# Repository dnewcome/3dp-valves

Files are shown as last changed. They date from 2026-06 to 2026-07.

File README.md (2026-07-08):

# 3dp-valves

A **parametric, 3D-printable solenoid valve & manifold system** for compressed gas —
shop air and (regulated, low-pressure) propane/butane for flame effects, plus pneumatic
cylinder control. Fluid schematics are modeled as composable solid parts in
[build123d](https://github.com/gumyr/build123d) and exported as clean, watertight STLs.

The idea: replace expensive miniature gas valves and manifolds with cheap printed blocks
that share a standard mating-face **port interface** (port + TPU gasket groove + bolt
pattern), so manifold configurations are assembled from composable blocks.

The repo now has two subsystems:
- **Valves** — direct-acting solenoid poppet valves + manifolds for compressed gas (below).
- **Pumps** — **two versions** of a solids-handling positive-displacement pump for fluids
  full of suspended solids (glass beads in mineral oil): a **horizontal S-valve** pump
  ([`PUMP.md`](PUMP.md)) and a **vertical submersible** rotary-distributor pump
  ([`VPUMP.md`](VPUMP.md)). Both are kept and maintained.

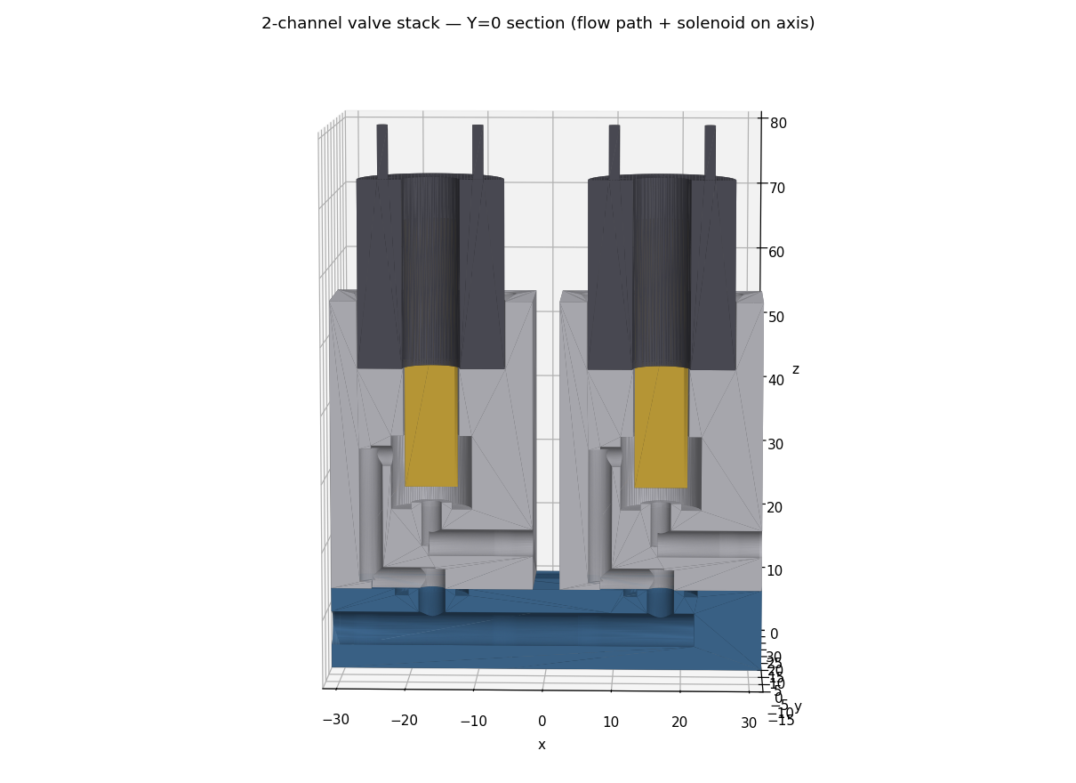
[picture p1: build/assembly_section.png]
2-channel valve stack, Y=0 section


## Design

A single channel is a **direct-acting, normally-closed, pressure-to-close poppet valve**:

```
  inlet (manifold, bottom) ─► -X riser ─► chamber  (supply surrounds the poppet)
                                              │  poppet lifts off the seat
                                              ▼
                                       orifice ─► +X outlet
```

- **Pressure-to-close** — supply fills the chamber and presses the poppet onto the seat,
  so pressure *helps* seal. The return spring is light (just reseats at zero pressure);
  the solenoid opens against P × orifice-area + spring, pulling from the seated position
  where the magnetic gap is smallest and coil force is greatest.
- **Direct-acting** (coil force only) — required for low-pressure / low-differential gas.
- **Normally-closed** — fail-safe (de-energized = shut).
- Tradeoff: the coil sets the max openable orifice (`A_max ≈ F_coil / P`) — generous at
  25 psi propane, tight (~Ø3) at 100 psi air. See [`BRIEF.md`](BRIEF.md).

See [`BRIEF.md`](BRIEF.md) for scope, [`RESEARCH.md`](RESEARCH.md) for solenoid/valve
selection and the duty-cycle / direct-vs-pilot reasoning, and
[`PRINT_AND_TEST.md`](PRINT_AND_TEST.md) for materials and the pressure-test procedure.

## Parts

| Module | Output | Material |
|---|---|---|
| `cad/interface.py` | shared port interface (constants, bolt pattern) | — |
| `cad/solenoid_block.py` | single valve body block | SLA rigid resin |
| `cad/poppet.py` | moving poppet | SLA rigid resin |
| `cad/tpu_disc.py` | flat sealing gasket | **FDM TPU ~95A** |
| `cad/manifold.py` | 1-inlet → 2-channel supply manifold | SLA rigid resin |
| `cad/solenoid_model.py` | reference coil + plunger (for fit only) | **bought, not printed** |
| `cad/assembly.py` | full + Y=0 section render (STL + PNG) | — |

Dimensions are chained by imports (`tpu_disc → poppet → solenoid_block → interface ←
manifold`), so changing one interface constant and rebuilding keeps every part in sync.

## Build

```bash
make deps        # pip install build123d trimesh matplotlib manifold3d
make             # build all parts + assembly/section render into build/
make help        # list targets (parts, assembly, clean, ...)
```

Or run a single script directly, e.g. `python3 cad/solenoid_block.py`. Each script
prints a sanity line (bounding box, body count, watertight flag). The Makefile tracks
the import chain, so editing `interface.py` rebuilds every dependent part.

## Pumps (solids-handling) — two versions

Where the valve blocks are all *small* precision orifices and poppet seats, the pumps are
the opposite — **large, clear, unobstructed passages** so suspended solids (glass beads in
mineral oil) never meet anything smaller than themselves. Both are positive-displacement,
run two cylinders 180° out of phase off one crankshaft, and share the same bead-safe parts
and clog guard (every wetted passage ≥ 4× the design bead, enforced at build). They differ
in orientation and directional valve:

| Version | Directional valve | Shaft | Best for | Port coverage | Docs |
|---|---|---|---|---|---|
| **Horizontal S-valve** | swinging **S-tube** | horizontal crank | bench / open-top hopper | ~41% (plain eccentric → wants a dwell cam) | [`PUMP.md`](PUMP.md) |
| **Vertical submersible** | coaxial **rotary distributor** | vertical shaft | running **submerged** | **~89%** (kidney arc = free dwell) | [`VPUMP.md`](VPUMP.md) |

A MuJoCo timing sim measures the port coverage of each (`sim/pump_sim.py`, `sim/vpump_sim.py`).

### Horizontal S-valve pump

A big swinging **S-tube** alternately connects each cylinder to the discharge — nothing
small to jam. The sim found a plain crank eccentric seals the discharging port only ~41% of
the cycle, so the swing wants a **dwell cam**. Full write-up in **[`PUMP.md`](PUMP.md)**.

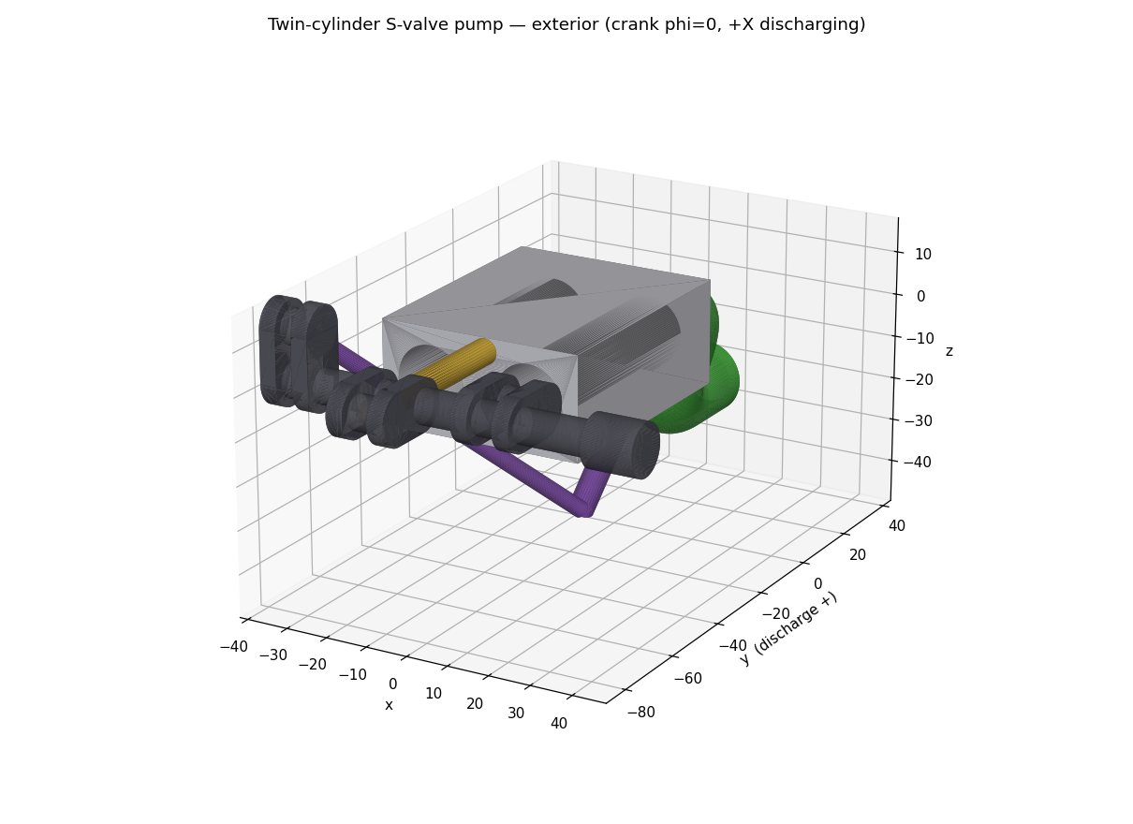
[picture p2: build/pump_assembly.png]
Twin-cylinder S-valve pump — exterior


```bash
make pump            # build the pump parts + assembly/section renders
make mujoco          # interactive timing sim (watch the swing track the ports)
```

### Vertical submersible pump

The vertical shaft makes the directional valve a **rotary distributor** coaxial with the
drive, which gives the dwell for free (**~89%** of the cycle sealed). Opposed cylinders,
90° up-piping, output riser to the surface. Full write-up in **[`VPUMP.md`](VPUMP.md)**.

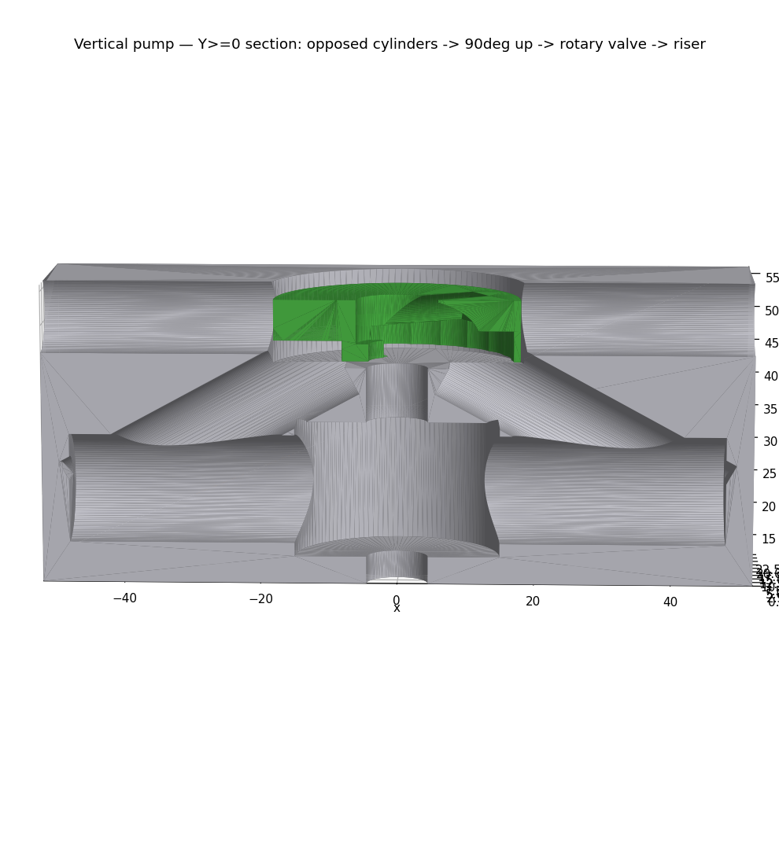
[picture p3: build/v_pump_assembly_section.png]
Vertical submersible pump — section


```bash
make vpump           # build the vertical submersible pump + renders
make vmujoco         # interactive timing sim of the rotary distributor (~89% coverage)
```

## Status

- **Valves:** working MVP — one complete sealed channel + a 2-channel manifold, all
  watertight. Next: print and pressure-test a single channel at 25 psi.
- **Pumps:** **two** working versions kept side by side — the horizontal S-valve pump
  ([`PUMP.md`](PUMP.md)) and the vertical submersible rotary-distributor pump
  ([`VPUMP.md`](VPUMP.md)). All parts watertight, timing simulated for both. Open details
  (dwell cam / rotary-union seal, hopper, bench test) are tracked in their docs.

Not yet modeled: the A/B + exhaust 2-way cylinder valve (pneumatics stretch) and a
schematic-driven manifold generator.

## Safety

Printed parts for **flammable gas**. Test with **air first**, never debug leaks with fuel
gas, use a regulator + leak detector, and run propane only outdoors with upstream shutoff.
Low-pressure, regulated service only.

## License

MIT

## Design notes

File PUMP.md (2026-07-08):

# Twin-cylinder S-valve pump (solids-handling)

A **parametric, 3D-printable positive-displacement pump** that moves fluids carrying
suspended solids — here **glass reflective beads in mineral oil** — without clogging.
It borrows the concrete-pump trick: the only "valve" is a **fat swinging tube** whose
bore is far bigger than any bead, so there is no small orifice or seat to jam. Built in
[build123d](https://github.com/gumyr/build123d), same conventions as the valve blocks.

> This is the **horizontal** version (bench / open-top hopper). For running the pump
> **submerged**, see the [**vertical submersible version**](VPUMP.md) — same bead-safe
> parts, a vertical shaft, and a coaxial rotary distributor. Both are maintained.

See [`PUMP_BRIEF.md`](PUMP_BRIEF.md) for scope/decisions.

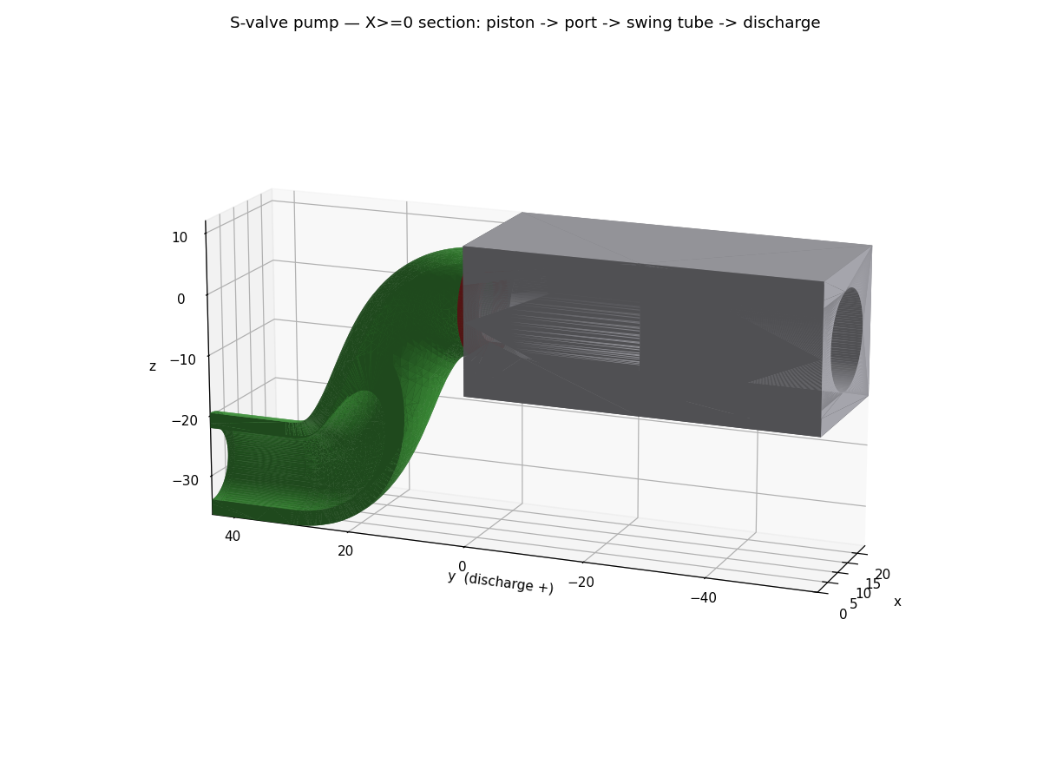
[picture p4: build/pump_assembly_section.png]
S-valve pump — X≥0 section: bore → wear ring → swing tube → discharge


## How it works

```
        hopper (open top, holds the bead-oil slurry, contains the S-tube)
   ┌──────────────────────────────────────────┐
   │   ●(-X port)            ●(+X port)         │  wear plate (y=0), two ports
   │        ╲                 ╱ ← S-tube mouth + TPU wear ring covers ONE port
   │         ╲_______________╱                  │
   │          (      S       ) gooseneck        │
   │           ╲____________╱                   │
   │             ▼ pivot = discharge axis ──────┼──► out
   └─────────────╫──────────────────────────────┘
   behind plate: two cylinders (bores along Y)
       piston ◄──┤├──► piston      ← 180° out of phase
                 ││
            conrods ─► ONE crankshaft ◄─ swing eccentric ─► rocks the S-tube
```

- **Two cylinders, 180° out of phase.** While one piston pushes slurry out through its
  port, the other retracts and **draws fresh slurry from the hopper** through its
  (uncovered) port. Output is near-continuous.
- **The S-tube is the whole valve.** Its outlet end is a fixed pivot on the discharge
  axis; its inlet **mouth swings** across the wear plate to cover exactly one port at a
  time. Because the mouth rides a circle centered on the pivot axis, and the plate is
  perpendicular to that axis, the mouth stays flat in the plate plane at **every** swing
  angle — one rigid tube seals two ports. Verified in `pump_assembly.py`: the swung
  mouth lands on the port at x=12.0, z=0.0.
- **Why it eats beads:** every bead-wetted passage — bore, port, tube — is ≥ **4× the
  design-max bead** (`pump_params.py` asserts `min_passage ≥ SAFETY × BEAD_D` at import,
  so the design *cannot* build if a passage is too narrow). Real glass reflective beads
  are much smaller than the 3 mm ceiling, so the margin is enormous.
- **Self-sealing wear ring.** A replaceable **TPU wear ring** on the mouth is pressed
  onto the plate by the discharge pressure itself. Mineral oil helps twice: it is
  viscous (keeps beads suspended, fills printed clearances) and lubricating (glass-in-oil
  grinds the seal far less than glass dry or in water). The ring is the designated wear
  item — print spares and swap it, exactly like the valve's `tpu_disc`.
- **One motor runs everything.** A single crankshaft reciprocates both pistons and, off a
  third eccentric, rocks the S-tube in time — no separate swing actuator.

## Parts

| Module | Output | Material |
|---|---|---|
| `cad/pump_params.py` | source of truth (dims, kinematics, `place()`, clog guard) | — |
| `cad/cylinder_block.py` | twin-cylinder body + wear plate + 2 ports | SLA rigid resin |
| `cad/s_tube.py` | swing tube (the S-valve) | SLA rigid resin |
| `cad/wear_ring.py` | replaceable mouth face seal | **FDM TPU ~95A** |
| `cad/piston.py` | piston (O-ring gland + conrod clevis) ×2 | SLA rigid resin |
| `cad/crankshaft.py` | single drive shaft (2 throws + swing eccentric) | printed or metal rod |
| `cad/pump_assembly.py` | full + X≥0 section render (STL + PNG) | — |

Dimensions chain from `pump_params.py` (like the valves' `interface.py`): change one
constant, rebuild, and every part + the assembly re-fit. Connecting rods and the swing
pushrod are drawn at assembly time as reference links between the crank pin centers.

## Build

```bash
make pump        # build all pump parts + assembly/section renders into build/
make             # build the valve stack AND the pump
python3 cad/pump_params.py    # print the clog-safety report (min passage vs bead)
```

Each part script prints a sanity line (bbox, body count, watertight). The assembly prints
a manifest, the swing-registration proof, and a bbox trip-wire. Renders are snapshotted to
`cad/renders/pump/` (a dated visual changelog — see its `INDEX.md`).

## Print, assemble, bench-test

**Materials / hardware (bench scale, default params):**
- Rigid parts (block, S-tube, pistons): **SLA** rigid resin (smooth bores/seal faces).
- Wear ring: **TPU ~95A** (FDM) or flexible SLA resin — must be an elastomer to seal.
- Per piston: an O-ring (~Ø12 × 2 mm CS) for the gland, a wrist pin, a connecting rod.
- Crankshaft: print it, or use a metal rod with printed cheeks for stiffness.
- A geared **DC/BLDC motor** (mineral oil is viscous → give yourself torque headroom).
- **Mineral-oil compatibility check (do before soaking):** PETG, TPU, and fully-cured
  SLA resin are generally fine with mineral oil; verify your specific resin/filament
  (soak a coupon for a few days and check for swelling/softening) before long runs.

**Bench test:**
1. Turn the crank **by hand** first, dry: confirm the pistons reciprocate 180° apart and
   the S-tube rocks fully onto each port at the piston dead-centers (this is the timing to
   get right — see below).
2. Fill the hopper with plain **mineral oil** (no beads yet). Hand-crank and confirm it
   primes and moves oil out the discharge with no leaks at the wear ring or walls.
3. Add **glass beads** to the slurry and repeat — watch for smooth, clog-free discharge.
   Then couple the motor.

## Drive timing — simulated (the risky bit)

The riskiest open question was whether a **single crankshaft** can rock the S-tube so its
mouth stays sealed on the *discharging* cylinder's port for that whole stroke. The MuJoCo
bench `sim/pump_sim.py` plays the real CAD meshes through the crank kinematics (imported
from `pump_params.py`) and measures **port coverage** — how far the mouth sits from the
discharging port vs crank angle.

swing timing: sine vs dwell

**Two findings — both change the drive design:**

1. **A plain eccentric will not do — you need dwell.** A simple crank eccentric gives
   *sinusoidal* swing: the mouth lines up on the port only for an instant at mid-stroke and
   is badly misaligned (up to ~12 mm) at the stroke ends — the discharging cylinder leaks
   back to the hopper most of its stroke. Quantified: the discharging port is sealed only
   **~41 %** of the cycle with a sine profile, vs **~82 %** with a dwell profile (parks the
   mouth on the port, flips fast at the dead centers where piston velocity ≈ 0 so little
   flow is lost). Run it: `make mujoco` (interactive), `make mujoco-demo` (gif + figure).
2. **The swing axis is perpendicular to the crank axis.** The crankshaft turns about **X**
   but the S-tube swings about **Y**, so a single in-plane pushrod *cannot* couple them
   (the schematic pushrod in the CAD render is exactly that — schematic). The swing needs a
   **right-angle take-off**: a bevel/crown gear driving a crank coaxial with the S-tube
   pivot, or a **dwell cam** on the crankshaft with a follower. The cam is attractive
   because it can bake the dwell profile from finding (1) directly into its shape.

**Design implication:** drive the pistons off the crankshaft as planned, but drive the
swing with a **dwell cam** (or an indexing mechanism) coaxial-ish with the pivot — not a
plain eccentric + pushrod. Widening the ports into **kidney slots** along the swing arc
buys extra overlap margin on top of the dwell.

## Status & next

Working first slice: block + swing S-tube + TPU wear ring + pistons + single crankshaft,
all watertight; the section proves the bead-safe flow path; the swing geometry is verified;
and the drive timing is simulated (above).

**Next, roughly in order:**
1. **Design the swing dwell mechanism** — a cam profile (or bevel-gear + rocker) that
   realizes the ~square-wave dwell the sim showed is needed, with a right-angle take-off
   from the crankshaft. Then re-sim to confirm ≥ ~90 % sealed.
2. **Hopper** — an open-top shell in front of the plate that holds the slurry and houses
   the swinging tube (its own part; currently omitted so the mechanism is visible).
3. **Discharge rotary seal** — a fixed collar the S-tube's discharge stub spins in.
4. **Kidney ports** — elongate the plate ports along the swing arc for overlap timing
   (round ports work; kidneys smooth the changeover).
5. **Scale to your beads** — set `BEAD_D` to your real bead size and rebuild; the clog
   guard keeps every passage safe automatically.

## Safety

Mineral oil is combustible (high flash point) and messy — this is **not** a food-safe or
pressure-rated device. Bench/art use at low head only. Contain spills; glass beads in oil
are slippery. If you ever swap to a volatile carrier, reassess everything.

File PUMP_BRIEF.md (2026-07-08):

# 3dp-pump — kickoff brief

A **solids-handling pump** subsystem for the 3dp-valves repo. Where the valve blocks
are all *small* precision orifices + poppet seats, the pump is the opposite: **large,
clear, unobstructed passages** so suspended solids never hit anything smaller than
themselves.

- **Problem:** Pump glass reflective beads suspended in **mineral oil** for an art
  project, with **zero clogging** — no bead-wetted passage or valve may ever narrow
  below the largest bead.
- **Done looks like:** One motor turns; two printed cylinders reciprocate 180° out of
  phase; a swinging **S-tube** valve alternately connects each cylinder to the outlet;
  bead-laden mineral oil moves continuously across the bench and **never jams**.
- **Not now:** High pressure/head, self-priming from a deep source, long-life / wear
  rating, and any flame-FX or existing-solenoid-valve integration. Bench scale,
  near-zero back-pressure.
- **First slice:** A parametric **twin-cylinder S-valve pump core** in build123d — two
  cylinder bores, the swing **S-tube**, and the **wear-plate + replaceable TPU
  wear-ring** sealing face — sized so every bead-wetted passage stays well above the
  largest bead, exporting clean watertight STLs. The pump analog of
  `solenoid_block.py` + `poppet.py`, reusing this repo's flat-TPU-seal trick.
- **Open question (riskiest):** The **swing-tube-to-wear-plate seal** on a *printed*
  part — can a pressure/spring-loaded TPU wear ring seal oil against a printed plate
  while beads sweep across it, and can a **single crankshaft** rock the S-tube in sync
  with the pistons (cam or second throw) rather than a separate actuator? Sim-able
  first with the repo's MuJoCo skill.
  - **Update (simulated, `sim/pump_sim.py`):** a plain eccentric gives *sinusoidal*
    swing that seals the discharging port only ~41 % of the cycle; a **dwell** profile
    gets ~82 %. And the swing axis (Y) is perpendicular to the crank axis (X), so the
    swing needs a **right-angle take-off + dwell cam**, not a plain pushrod. See
    [`PUMP.md`](PUMP.md) → *Drive timing*. Seal-against-abrasion is still open (bench test).

## Why the S-valve (swing tube), not a poppet/ball check

Concrete pumps move fluid full of rocks because the only "valve" is a **fat tube whose
bore is bigger than any rock**. The tube's outlet end is a fixed pivot at the discharge;
its inlet mouth swings across a **wear plate** with two kidney ports (one per cylinder),
connecting exactly one cylinder to the outlet while the other draws from the hopper. The
mouth seals against the plate via a **wear ring** loaded by discharge pressure —
self-sealing, but self-wearing (the caption "…that maybe seems like a great idea, but…").
Mineral oil is a *friendly* carrier here: viscous (keeps beads suspended, fills printed
clearances) and lubricating (glass-in-oil grinds the seal far less than glass dry/in
water).

## Key decisions locked
- **Architecture:** twin-piston + **S-tube swing valve** (positive displacement, large
  clear passages, near-continuous output).
- **Drive:** **single motor + crankshaft** — one shaft reciprocates both pistons 180°
  out of phase *and* rocks the S-tube in time (cam or second throw), so one motor runs
  everything.
- **Carrier / solids:** glass reflective beads in mineral oil, bench scale, low head.
- **Seal:** replaceable **TPU wear ring** on the swinging mouth against a printed wear
  plate (reuses the repo's TPU-seal material + method).
- **Materials check (before soaking):** confirm mineral-oil compatibility of the chosen
  print resin/filament (PETG, TPU, cured SLA are generally fine).

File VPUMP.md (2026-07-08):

# Vertical submersible S-valve pump (rotary distributor)

A **vertical-shaft variant** of the [twin-cylinder pump](PUMP.md), built to run **submerged**
with the drive shaft vertical. Re-orienting the shaft to vertical makes the directional
valve **coaxial** with the drive — so the "cam" that alternates the output becomes a
**rotary distributor** turning on the same shaft. That change also solves the horizontal
pump's timing problem for free: a continuously-rotating distributor is a square-wave
selector, so it holds the **dwell** the [sim](PUMP.md#drive-timing--simulated-the-risky-bit)
showed a plain eccentric can't.

Vertical pump — Y≥0 section: opposed cylinders → 90° up → rotary valve → riser

## How it works (bottom → top)

```
                    ▲ output riser (up to the surface, past the waterline)
                    │
         ┌──────────┴──────────┐  valve chamber
         │      [ROTOR]        │  rotary distributor keyed to the shaft:
         │   kidney → riser    │   ~160° kidney routes the DISCHARGING port up to the
         │   relief → bath     │   riser; opposite relief opens the OTHER port to the bath
         ├─────────┬───────────┤  valve plate: 2 ports (±X), 180° apart
   port ─┤  90° up-gallery     ├─ port      each cylinder's outer port turns UP + inward
         │         │           │
   [===piston→]  shaft  [←piston===]  two OPPOSED cylinders (bores along X), ports outward
         │   crank throw       │   one shared crank throw drives both, 180° out of phase
         └─────────┬───────────┘
                   │ shaft
                   ▼ motor coupling (sealed, at the bottom)
```

- **Vertical shaft, opposed cylinders.** Two collinear cylinders (bores along X) share one
  crank throw, so their pistons run 180° out of phase — one discharges while the other
  draws from the bath. Opposed (rather than side-by-side) because a *central* vertical shaft
  makes collinear cylinders a clean, zero-offset slider-crank with ports that land **180°
  apart** on the valve plate — exactly what the rotary distributor wants.
- **Rotary distributor = the "cam".** A rotor keyed to the shaft carries a ~160° **kidney**
  on its underside. As it turns, the kidney connects whichever port is discharging up
  through the rotor's central bore to the **riser**, while an opposite **relief** opens the
  other port to the bath for suction. No poppets, no check valves — nothing small to clog.
- **Dwell for free.** Because the kidney is a 160° arc, the discharging port stays connected
  for ~160° of every 180° stroke: **~89% of the cycle sealed** (`python3 cad/vpump_params.py`),
  versus **~41%** for the horizontal plain eccentric. The ~20° gaps land at the dead centers,
  where piston velocity ≈ 0 and little flow is lost.
- **90° internal piping.** Each cylinder's horizontal discharge turns **up** to the coaxial
  valve, so the output leaves **vertical — 90° to the cylinders** — and rises out of the fluid.
- **Submersible.** The whole body runs under the fluid; the un-selected cylinder simply
  draws from the surrounding bath (vent to the valve chamber). Every bead-wetted passage
  stays ≥ 4× the design bead (the clog guard in `vpump_params.py` includes the kidney slot).

## Drive timing — simulated

The MuJoCo bench `sim/vpump_sim.py` plays the **real vertical-pump meshes** through the crank
kinematics and measures the same port coverage the [horizontal bench](PUMP.md#drive-timing--simulated-the-risky-bit)
used — closing the loop: where a plain swinging eccentric sealed the discharging port only
**~41%** of the cycle, the coaxial rotary distributor holds it **~89%**, with no cam profile
to tune. The kidney's 160° arc *is* the dwell; the only gaps are the ~20° dead-bands at each
changeover, where piston velocity ≈ 0.

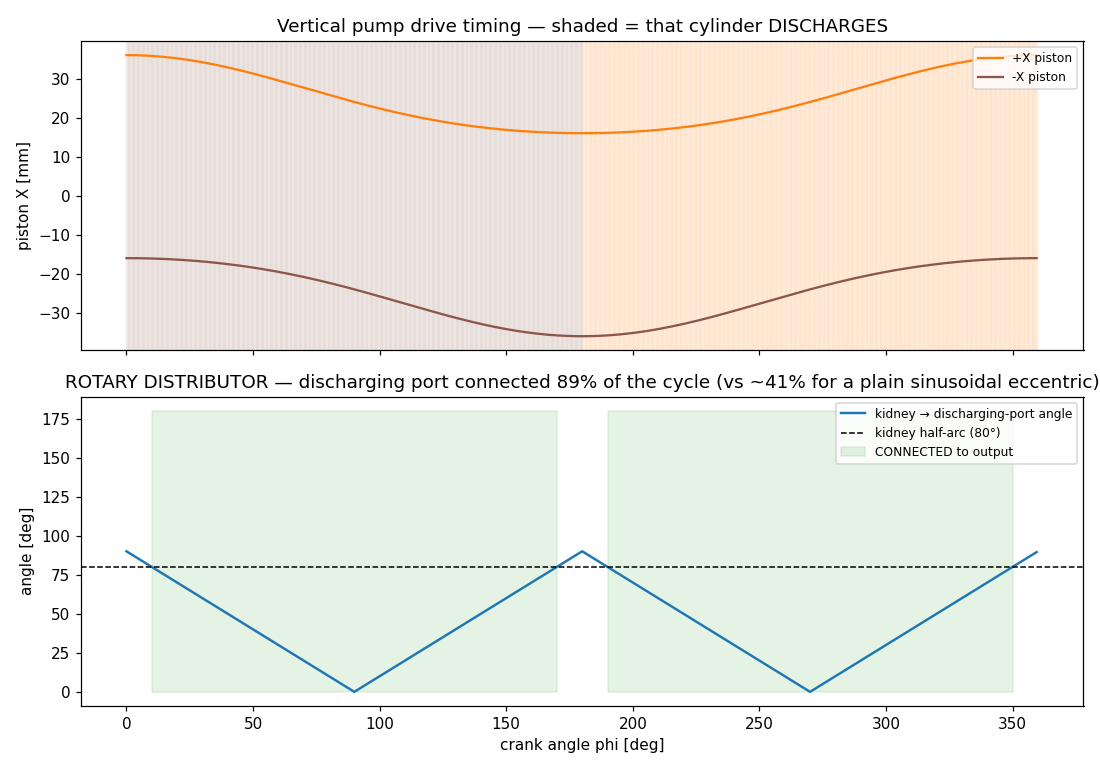
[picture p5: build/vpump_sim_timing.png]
vertical timing: rotary distributor coverage


```bash
make vmujoco          # interactive: watch the rotary valve track the discharging ports
make vmujoco-demo     # headless: coverage figure + animated gif
```

The interactive/gif view ghosts the block so the opposed pistons, crank, conrods, and the
green rotor are all visible turning inside the submersible body.

## Parts

| Module | Output | Notes |
|---|---|---|
| `cad/vpump_params.py` | source of truth (reuses bore/bead/piston consts + kinematics + clog guard) | — |
| `cad/v_block.py` | body: opposed bores + 90° galleries + valve plate + chamber | SLA rigid |
| `cad/v_rotor.py` | rotary distributor (kidney + suction relief + central output) | SLA rigid; wear item |
| `cad/v_crankshaft.py` | vertical shaft: crank throw + rotor key + coupling | printed or metal |
| `cad/piston.py` | piston ×2 (**reused** from the horizontal pump) | SLA rigid |
| `cad/v_pump_assembly.py` | vertical stack render + section + waterline | — |

```bash
make vpump                    # build the vertical pump parts + renders
python3 cad/vpump_params.py   # clog report + dwell coverage vs a plain eccentric
```

The assembly verifies the valve timing (the rotor kidney sits over whichever port is
discharging) before it renders.

## Decisions & honest open details (this is a v1 concept model)

Locked: vertical shaft · opposed cylinders + one crank throw · coaxial rotary distributor ·
90° up-galleries · riser output · submerged suction (no check valves).

Deliberately left for the next pass (documented so nothing reads as finished that isn't):
1. **Rotary-union seal.** The rotor's central output (rotating) meets the stationary riser
   at the top — that transfer needs a face seal (or an annular collector). Modeled as a
   straight hand-off here; a TPU face seal on the rotor top is the intended fix (same
   wear-item philosophy as the horizontal pump's ring).
2. **Motor placement.** Modeled **motor-below** (a sealed submersible unit at the bottom) so
   the output can rise straight up the center. For a **dry motor above the fluid**, the shaft
   runs up the center and the output takes an **offset riser** with a rotary transfer — a
   variant, not modeled yet. Say which you want and I'll build it.
3. **Suction vent detail.** The valve chamber vents to the bath through the block ends; the
   rotor's relief arc opens the non-selected port to it. The exact vent/relief sealing wants
   a bench check.
4. **Galleries** are modeled as straight routed passages (turning horizontal discharge up to
   the vertical valve); production would fillet/optimize them.
5. **Parallel vs opposed.** You picked "parallel"; I built **opposed** because a central
   vertical shaft makes it far cleaner (zero-offset slider-crank, ports naturally 180° apart
   for the rotary valve). Easy to switch to strict parallel with routed galleries if you want.

## Safety

Same as the [horizontal pump](PUMP.md#safety): mineral oil, bench/art use, low head, not
food-safe or pressure-rated. Submerged operation — keep the motor/electrics sealed and the
riser clear of the surface.

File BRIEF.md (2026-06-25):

# Flame-FX gas/pneumatic manifold — kickoff brief

- **Problem:** Sophisticated flame effects (and pneumatic cylinder control) normally
  need lots of expensive miniature gas valves + manifolds. Build a cheap, SLA-printed,
  parametric alternative where flow schematics become composable solid-modeled blocks.
- **Done looks like:** One printed inlet manifold block feeding **2 custom solenoid
  blocks**, each with a coil + ferrous plunger seating a TPU poppet against a printed
  seat, switching independent outputs on/off — holding 25 psi propane (target) /
  100 psi air (stretch).
- **Not now:** Gas-tightness of printed *walls* (SLA handles it); the A/B + exhaust
  2-way cylinder valve (stretch); full schematic→geometry compiler; flame-effect
  choreography / control electronics.
- **First slice:** A **single parametric solenoid block** in build123d — inlet/outlet
  ports, valve seat + orifice, TPU poppet groove, plunger guide bore, and coil bore —
  sized around one specific off-the-shelf coil + plunger, exporting a clean watertight
  STL. Get *one channel* sealing before manifolding two.
- **Open question (riskiest):** Coil pull vs. pressure on OPEN. With pressure-to-close
  (below), the spring is trivial but the solenoid must lift the poppet against
  P × orifice-area + spring. This caps the openable orifice: A_max ≈ F_coil / P.
  For a ~6 N coil (minus ~1 N spring): Ø6 at 25 psi (huge margin), but only ~Ø3 at
  100 psi. So Ø3 is comfortable for propane and right at the limit for 100 psi air —
  bigger pneumatic flow needs a bigger coil or a pilot/3-way (the A/B+exhaust stretch).

## Key decisions locked
- **Actuation:** Custom poppet + coil (fully parametric; we own sealing/force/spring).
- **Force orientation: PRESSURE-TO-CLOSE.** Supply fills the chamber and presses the
  poppet onto the seat, so pressure helps seal and the return spring is a light
  reseat-only spring (~0.5–1 N). The solenoid opens from the seated position, where
  the magnetic gap is smallest and coil force is greatest. (Beats pressure-to-open,
  where the spring is weakest exactly when it must hold against full pressure.)
- **Process:** SLA printing (good surface finish for seat/poppet sealing).
- **Pressures:** 25 psi propane (primary), 100 psi air/pneumatics (stretch).
- **Fallback under evaluation:** COTS miniature solenoid valves if custom poppet
  sealing proves unreliable.

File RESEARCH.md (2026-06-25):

# Solenoid & valve research

Research backing the actuation decisions in [BRIEF.md](BRIEF.md). Two paths:
the **custom poppet** (chosen) and a **COTS fallback** to de-risk sealing.

## Custom-poppet path — bare solenoids to design around

| Solenoid | Force / stroke | Duty | Notes |
|---|---|---|---|
| **Makermotor PN00121** (12V tubular push-pull) | 6N @ 10mm, 1.85A | continuous (listed) | Cheap (~$15–20), defined spec sheet — primary part to design around |
| **Generic 8mm-plunger push-pull** (Amazon/AliExpress) | 2–15N, 2–20mm stroke, 7–25W | continuous variants exist | Cheapest; specs vary by listing — buy & measure |
| **Murphy RP2307B / RP2309B** | 49–62N pull, 102–151N hold | continuous | Large/overkill, but shows pattern: hold force >> pull force |

**Key physics:** solenoid force is highest at end-of-stroke (smallest air gap).
A poppet seats at end-of-stroke — exactly where the coil is strongest. Design the
geometry so the magnetic gap is smallest at the sealed position. 100 psi × 3 mm
orifice ≈ 4.5 N seating force; the small 6 N unit clears it *if near-seated*.

## COTS fallback — drop-in valves if custom sealing flunks

**Propane / 25 psi:**
- **U.S. Solid 1/4" NPT brass + Viton, 12V NC** — rated water/gas/oil/fuel, ~$15–25. Credible cheap fallback.
- **AceCrew 1/2" Viton NC** — explicitly lists propane/butane.
- ⚠️ Most generic "12V solenoid valves" are water/air only (NBR) — NOT fuel-rated. Require Viton + brass/SS for propane.

**Pneumatics / 100 psi + A/B exhaust (stretch):**
- **SMC SY3000** / **Festo VUVG** — compact 3/2 & 5/2, base/manifold-mountable. Best integration path: printed block = manifold base, valve island bolts on. ~$30–60/valve.

## Three insights that shape the spec

1. **Direct-acting is mandatory.** Pilot-operated valves need ~5–10 psi differential to open; won't work at low pressure / zero flow. Custom poppet must be coil-force-only. Caps practical orifice size per coil.
2. **NC = fail-safe but fights continuous duty.** De-energized = closed (spring) is the safe default, but coil must stay energized to keep flow on, and cheap solenoids overheat held on. **Flame-FX poofers rescue this** — brief energization = intermittent duty, where small cheap solenoids thrive. *Held* pneumatic cylinders are the hard case (continuous-duty or latching coil).
3. **Latching/bistable solenoids** — pulse to switch, zero holding power, no heat. Good for held-open cases; adds driver complexity.
4. **Pressure-to-close, not pressure-to-open.** Orient the flow so supply pressure presses the poppet ONTO the seat (chamber = supply, orifice = outlet). Then the return spring only reseats at zero ΔP (light), and the coil opens from the seated gap where its force peaks. The opposite orientation makes the spring hold against pressure — and a compression spring is weakest when seated (least compressed), exactly when it must hold most. Cost of pressure-to-close: coil sets max orifice, A_max ≈ F_coil / P (≈Ø6 at 25 psi, ≈Ø3 at 100 psi for a 6 N coil).

**Net:** design the parametric block around a small continuous-duty 12V push-pull
(Makermotor-class), direct-acting, NC, **pressure-to-close** (gap-closes-at-seat) —
keep the U.S. Solid Viton valve as a drop-in fallback in the same manifold footprint.

## Sources
- Makermotor PN00121: https://makermotor.com/pn00121-12vdc-push-pull-solenoid-actuator-6n-at-10mm-stroke-1-85a/
- Murphy RP2307B: https://catalog.baileymotorequip.com/item/engine-controls/solenoid-drivers/item-1195
- Geeplus push-pull range: https://www.geeplus.com/push-pull-solenoids/
- U.S. Solid 1/4" brass Viton NC: https://ussolid.com/products/u-s-solid-electric-solenoid-valve-1-4-12v-dc-solenoid-valve-brass-body-normally-closed-viton-seal-html
- AceCrew Viton (propane/butane): https://www.amazon.com/VITON-Brass-Solenoid-Normally-Closed/dp/B07C627DVM
- SMC SY3000 5-port: https://www.smcusa.com/products/sy3000-5-port-solenoid-valve-all-types~128914
- Festo valves/manifolds: https://www.festo.com/us/en/c/products/industrial-automation/pneumatic-valves-and-valve-manifolds-id_pim23/
- Direct-acting vs pilot (min. differential): https://ussolid.com/blogs/solenoid-valve/differences-between-pilot-operated-and-direct-acting-solenoid-valves

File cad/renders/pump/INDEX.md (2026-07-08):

# pump render log

Visual changelog of the twin-cylinder S-valve pump. Newest at the bottom; never delete frames.

- 0001-core-exterior.png / 0001-core-section.png — 2026-07-07 — first slice: twin-cylinder
  block + swing S-tube + TPU wear ring + pistons + single crankshaft (2 opposed throws +
  swing eccentric). Section proves the bead-safe flow path bore -> port(ring) -> tube ->
  discharge. Swing geometry verified: mouth lands on the +X port.

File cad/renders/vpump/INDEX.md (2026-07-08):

# vertical submersible pump render log

- 0001-vertical-exterior.png / 0001-vertical-section.png — 2026-07-07 — first slice of the
  vertical submersible variant: opposed cylinders + one crank throw, coaxial rotary
  distributor (89% discharging-port coverage), 90° up-galleries, riser to the surface,
  motor-below. Timing verified (kidney over the discharging port).

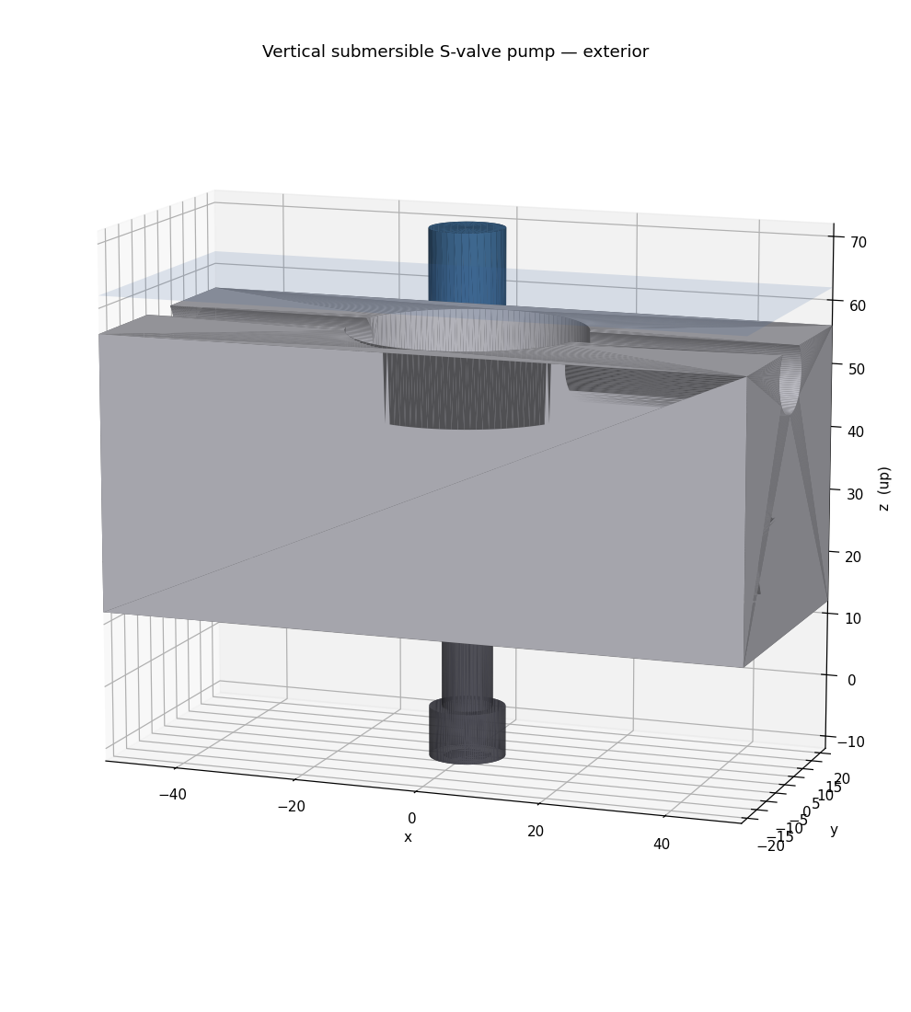
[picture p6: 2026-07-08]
cad/renders/vpump/0001-vertical-exterior.png

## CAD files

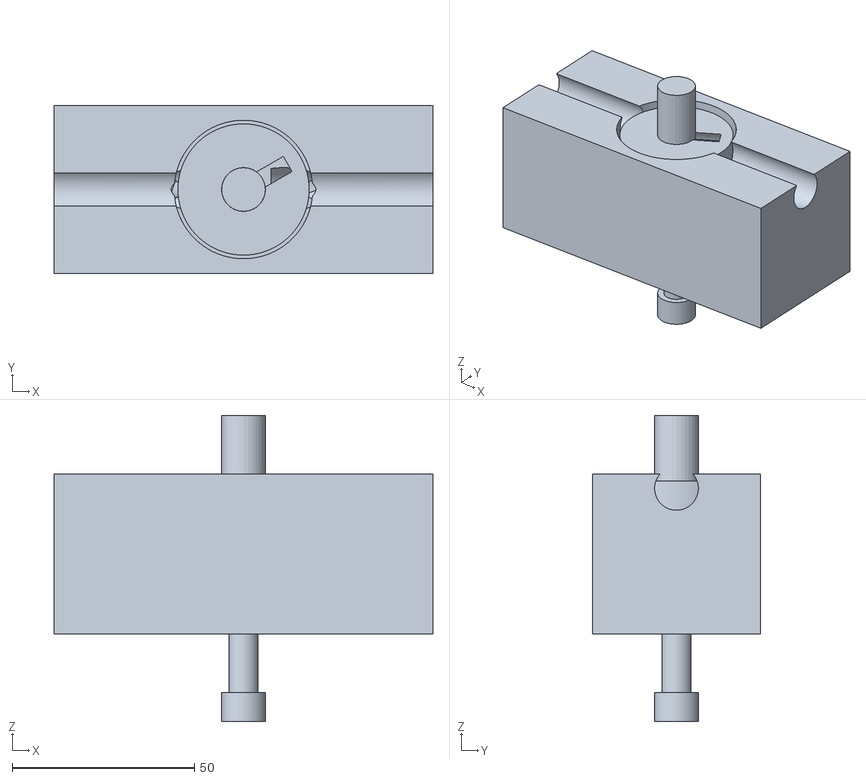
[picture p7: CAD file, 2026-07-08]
build/v_pump_assembly.stl
104.0 x 46.0 x 84.0

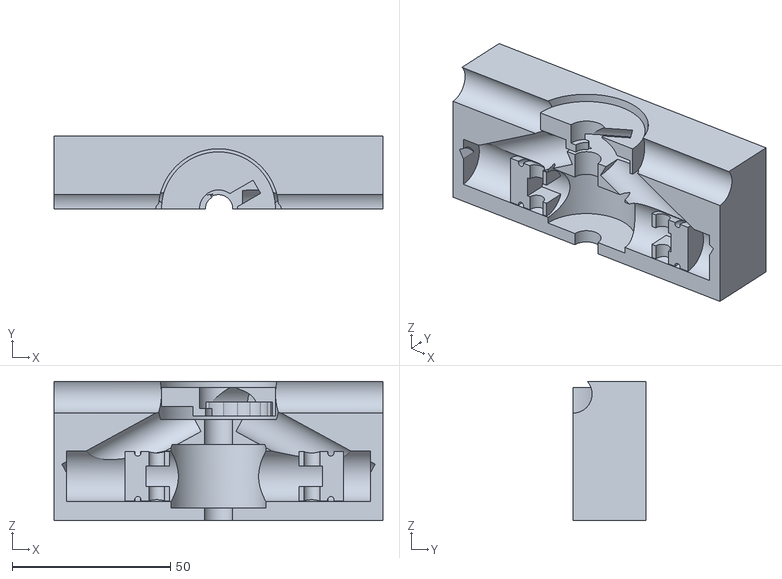
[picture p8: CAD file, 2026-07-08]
build/v_pump_assembly_section.stl
104.0 x 23.0 x 44.0

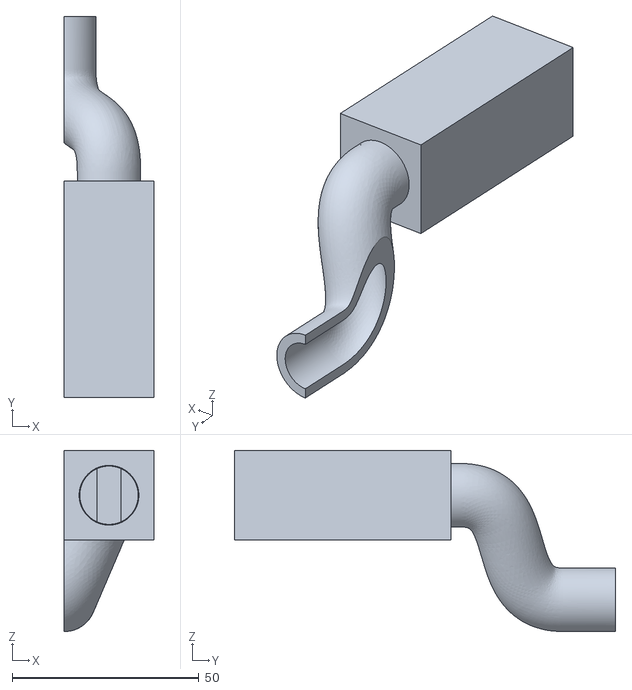
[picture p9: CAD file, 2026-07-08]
build/pump_assembly_section.stl
24.0 x 102.0 x 48.5

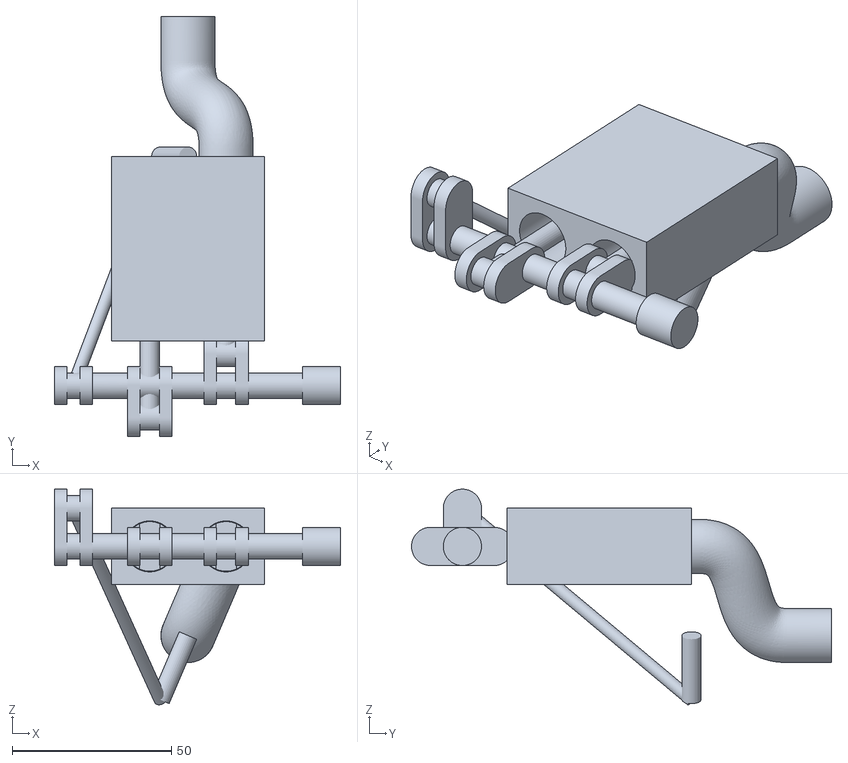
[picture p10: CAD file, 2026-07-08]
build/pump_assembly.stl
90.0 x 132.0 x 67.8

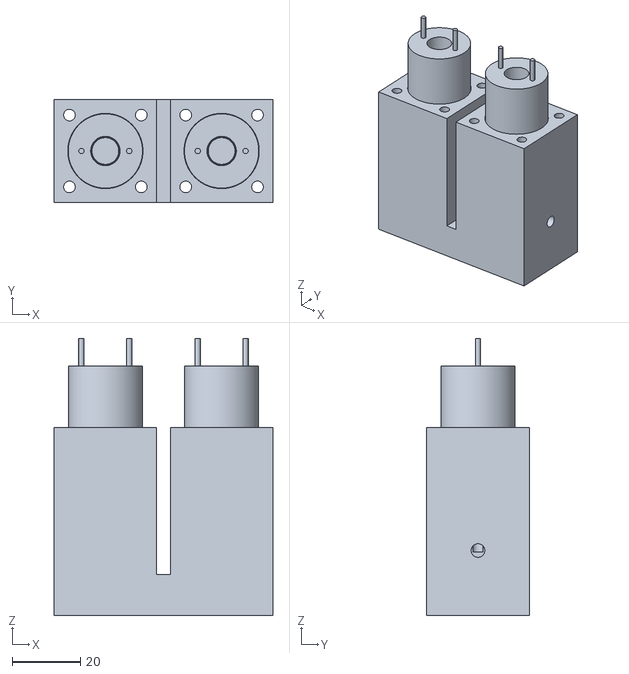
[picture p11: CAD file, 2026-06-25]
build/assembly.stl
64.0 x 30.0 x 81.0

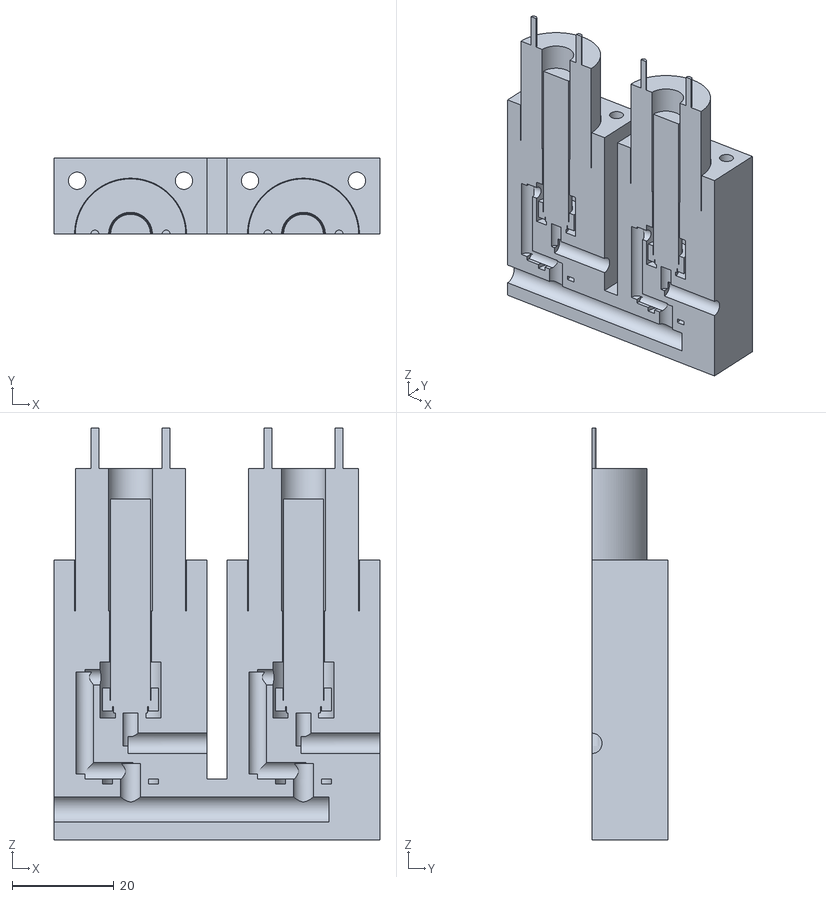
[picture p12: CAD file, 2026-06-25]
build/assembly_section.stl
64.0 x 15.0 x 81.0

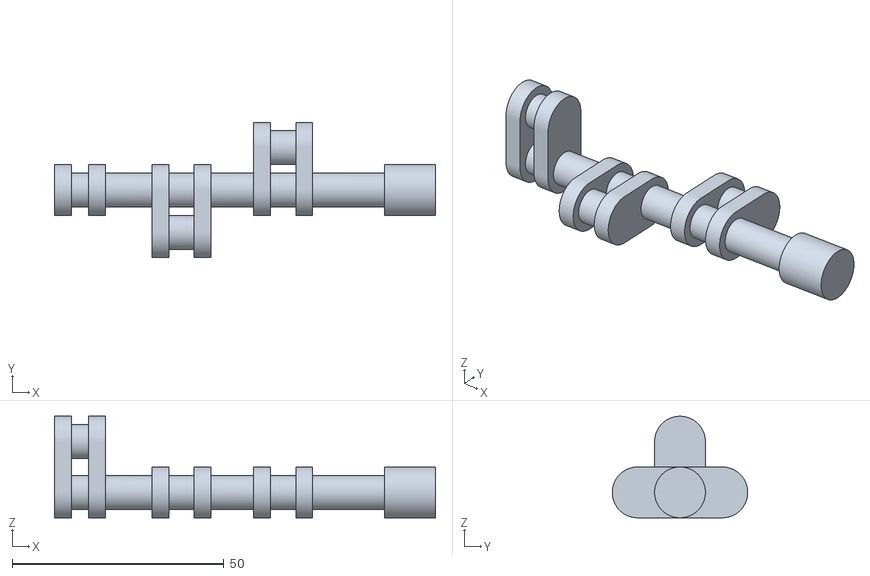
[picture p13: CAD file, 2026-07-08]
build/crankshaft.stl
90.0 x 32.0 x 24.0

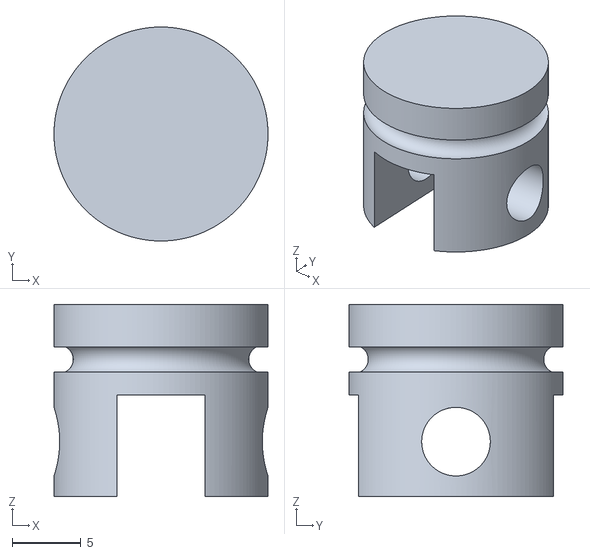
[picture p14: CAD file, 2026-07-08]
build/piston.stl
15.6 x 15.6 x 14.0

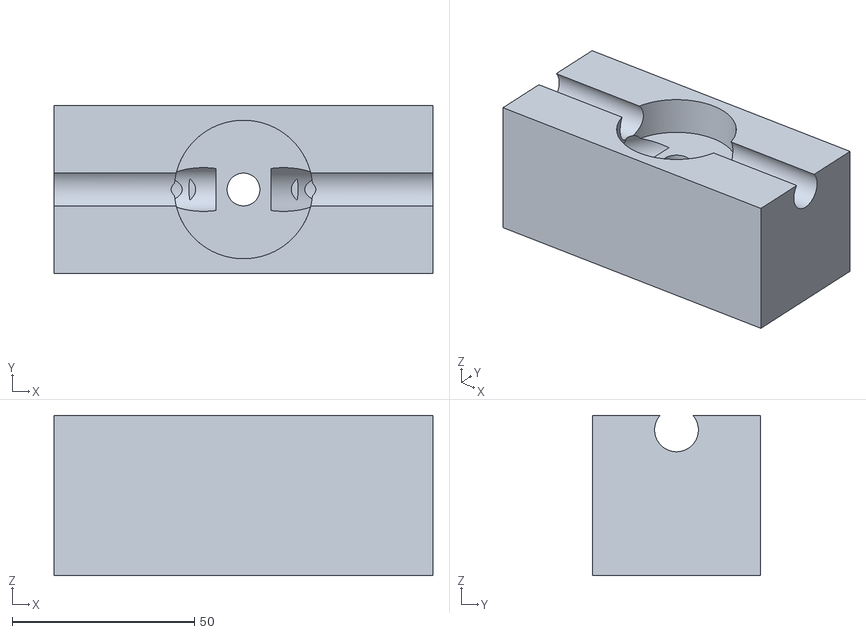
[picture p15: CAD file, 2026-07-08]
build/v_block.stl
104.0 x 46.0 x 44.0

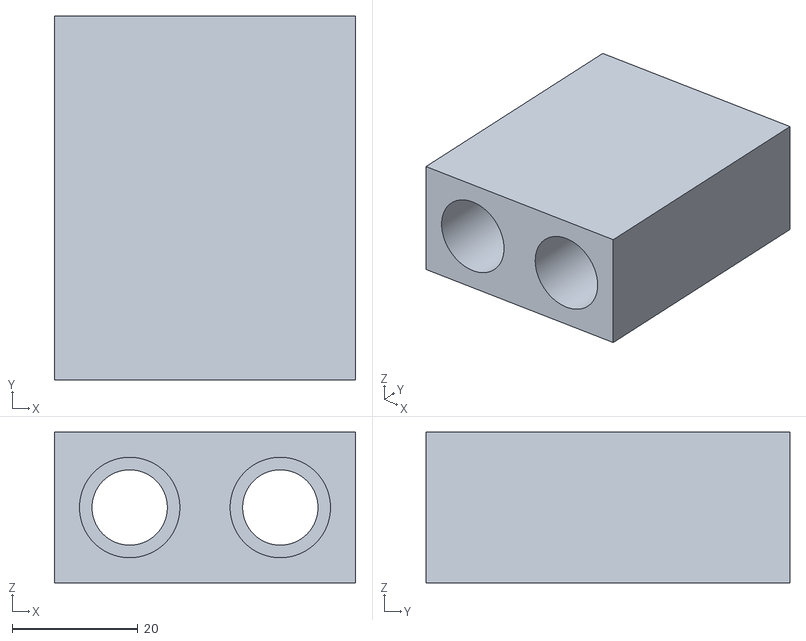
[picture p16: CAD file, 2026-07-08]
build/cylinder_block.stl
48.0 x 58.0 x 24.0

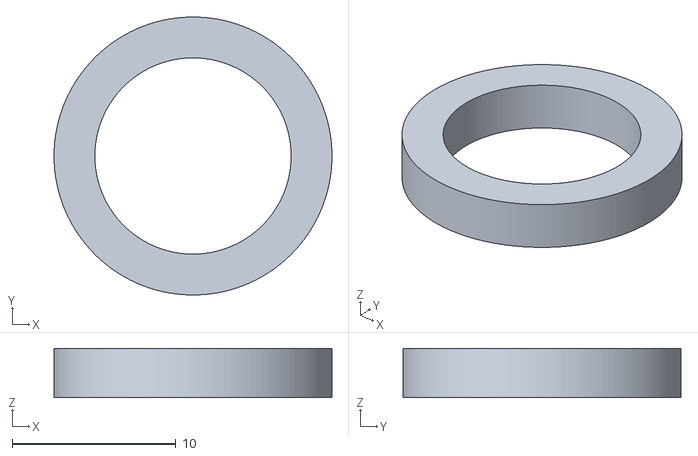
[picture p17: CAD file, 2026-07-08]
build/wear_ring.stl
17.0 x 17.0 x 3.00

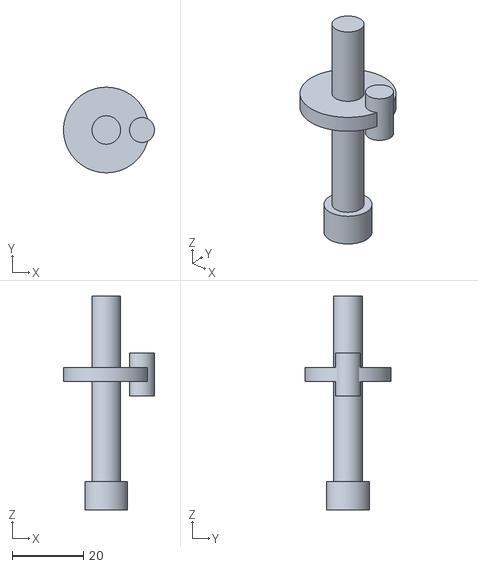
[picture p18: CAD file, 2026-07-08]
build/v_crankshaft.stl
25.5 x 24.0 x 60.0

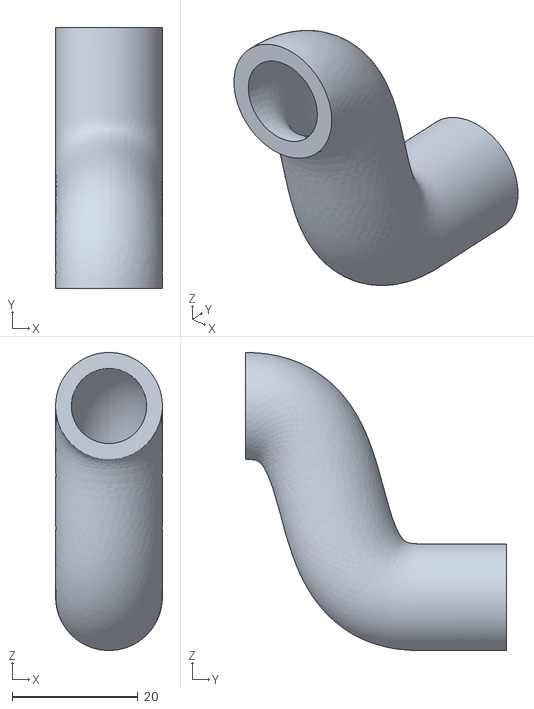
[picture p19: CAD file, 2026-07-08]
build/s_tube.stl
17.0 x 41.5 x 47.5

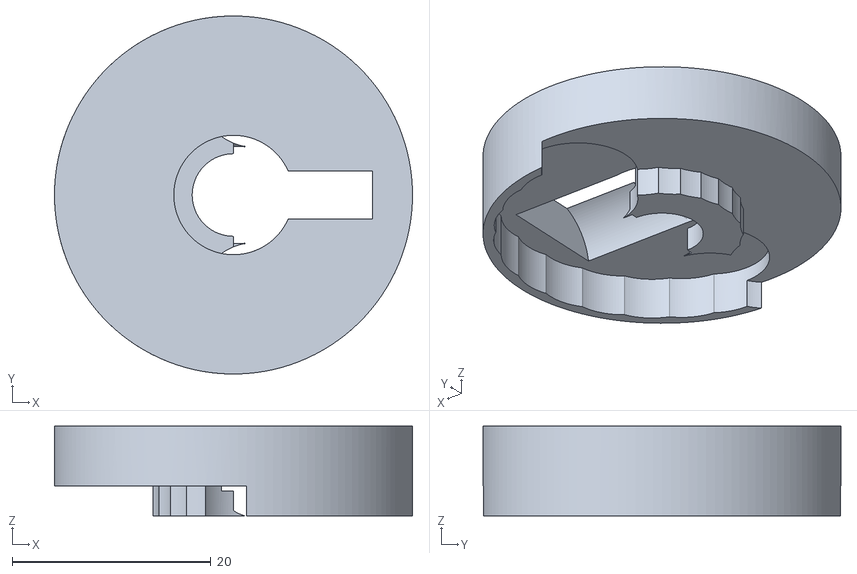
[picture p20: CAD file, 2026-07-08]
build/v_rotor.stl
36.0 x 36.0 x 9.00

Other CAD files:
build/solenoid_block.stl
build/solenoid_coil.stl
build/solenoid_plunger.stl
build/tpu_disc.stl
build/manifold.stl
build/poppet.stl

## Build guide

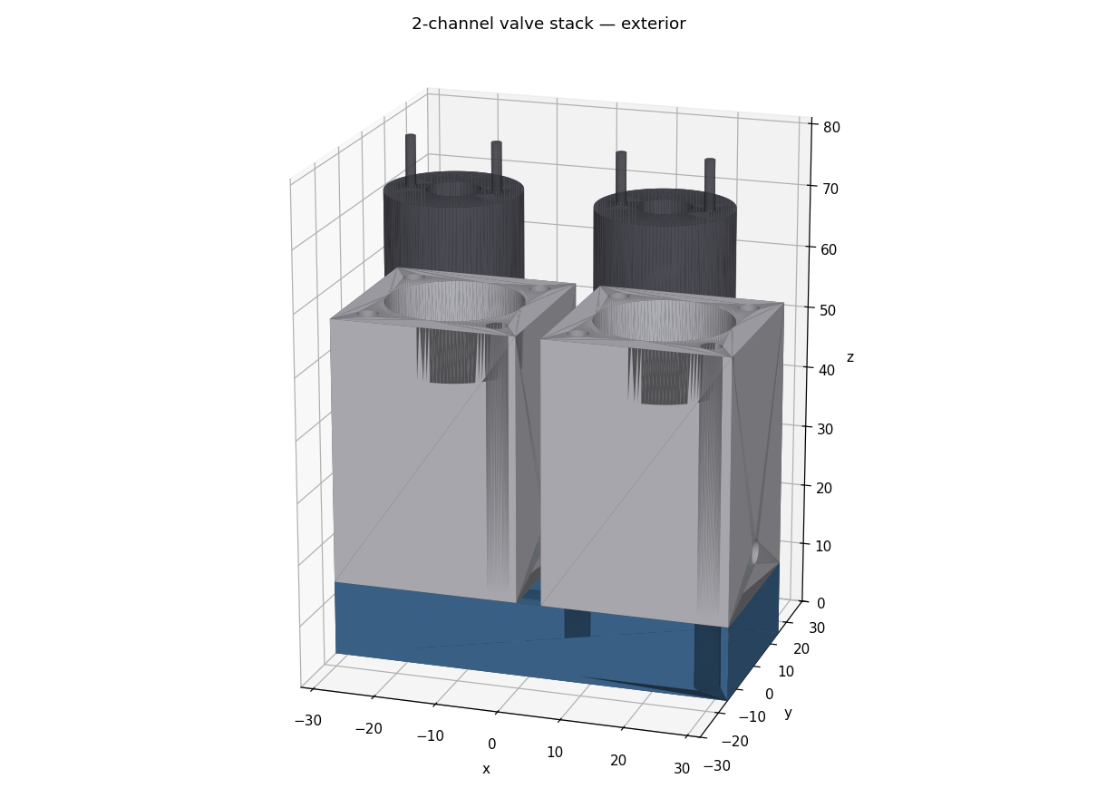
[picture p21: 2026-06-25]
build/assembly.png

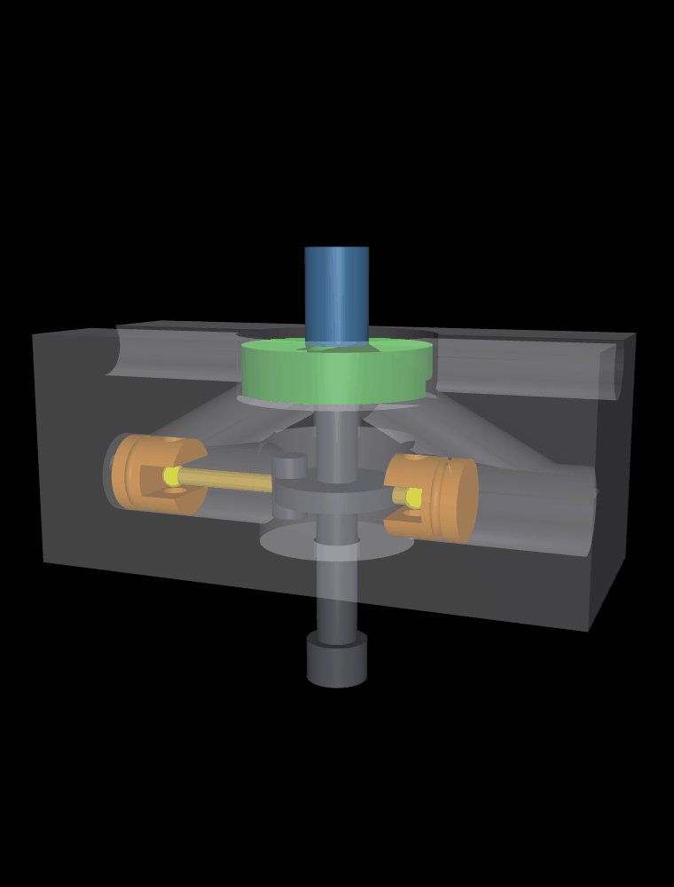
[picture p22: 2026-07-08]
build/vpump_sim.gif

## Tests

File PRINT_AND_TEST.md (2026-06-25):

# Print & bench-test guide

Goal: **prove one channel seals at 25 psi before printing the manifold.** Cheapest
possible learning — don't replicate an unsealed design.

## Parts & materials

| Part | File | Process / material | Notes |
|---|---|---|---|
| Valve body block | `build/solenoid_block.stl` | SLA, rigid resin | Orient coil bore up; supports off the +X outlet |
| Poppet | `build/poppet.stl` | SLA, rigid resin | Tiny — print a few spares |
| TPU gasket disc | `build/tpu_disc.stl` | **FDM, TPU 95A** (or flexible SLA resin) | Rigid SLA won't seal; needs an elastomer |
| 2-ch manifold | `build/manifold.stl` | SLA, rigid resin | Only after one channel passes |

> TPU is an **FDM** filament; the rigid parts are **SLA**. If you only have SLA, use a
> flexible resin for the gasket (Shore ~A80–95), or buy an O-ring (needs the wider-land
> variant — see `RESEARCH.md` / `BRIEF.md`).

## Bought hardware (per channel)

- 12V push-pull solenoid, **continuous-duty**, ~8 mm plunger, ~10 mm stroke
  (Makermotor PN00121 class). **Measure it and update `COIL_BORE_D` in `cad/solenoid_block.py`.**
- Return compression spring: OD ≈ 7 mm, free length ≈ 5–6 mm, **light** (~0.5–1 N). With
  the pressure-to-close layout it only reseats the poppet at zero pressure — supply
  pressure does the sealing. Sits in the chamber on the poppet top, bears on the ceiling.
  Don't oversize it: a stiff spring just makes the solenoid work harder to open.
- 4× M3 socket-head screws + heat-set inserts (for the manifold joint).
- Push-to-connect or barb fittings for the ports (tap the bottom inlet / +X outlet to taste).
- Thread sealant / PTFE tape rated for the medium.

## Assembly (single channel)

1. Press/glue the TPU disc into the poppet's bottom pocket (protrudes ~0.4 mm).
2. Bond the poppet onto the solenoid plunger tip (Ø8.1 bore). Verify the disc sits
   square — it must land flat on the Ø6 seat.
3. Drop the return spring into the chamber, insert poppet+plunger, seat the solenoid in
   the coil bore. De-energized, the spring must hold the poppet firmly on the seat.
4. Fit inlet/outlet fittings.

## Pressure test (do this BEFORE trusting it with propane)

**Test with AIR first. Never debug leaks with fuel gas.**

1. Cap the outlet. Connect a regulated air supply to the inlet through a gauge.
2. **Energize check:** at 0 psi, energize the coil — poppet should lift audibly/freely.
   De-energize — it must snap closed.
3. **Leak ramp:** apply 5 psi (de-energized). Brush soapy water over the seat area and
   every printed wall / joint. No bubbles = good. Hold 2 min, watch the gauge for decay.
4. Step to 10, then 25 psi (propane target), repeat the bubble + decay check at each step.
5. **Flow check:** open the outlet, energize — confirm full flow; de-energize — flow stops
   cleanly with no creep.
6. Only after a clean 25 psi hold should you consider propane (and only outdoors, with a
   regulator, leak detector, and a way to shut off upstream).

## What to watch / likely failure modes

- **Seat leak:** disc not flat, land print layer lines, or too little spring force.
  Try more gasket protrusion (raise `PROTRUDE` in `tpu_disc.py`) or a stiffer spring.
- **Wall weep:** SLA should be gas-tight; if it weeps, the print is under-cured or thin —
  thicken walls (raise the envelope) or re-cure.
- **Coil overheating:** if held energized for a flame *hold* (not a poof), the cheap coil
  may cook — see the duty-cycle notes in `RESEARCH.md`.

## Pneumatic / 100 psi note

Pressure-to-close means the coil must OPEN against P × orifice-area (+ light spring).
At 100 psi / Ø3 that's ≈ 4.9 N + ~1 N ≈ 6 N — right at a small coil's limit, but the
pull happens from the seated position where coil force peaks, so it's feasible. Bigger
pneumatic flow (larger orifice) needs a stronger coil or a pilot/3-way. The A/B+exhaust
2-way cylinder valve is a separate (stretch) block — not yet modeled.

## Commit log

2026-06-24 Parametric 3D-printable solenoid valve & manifold system
    Composable build123d blocks for compressed gas/air control:
    - shared port interface (port + TPU gasket groove + bolt pattern)
    - direct-acting NC poppet solenoid valve body + poppet + TPU gasket
    - 1-inlet 2-channel supply manifold
    - assembly + Y=0 section render
    - brief, solenoid/valve research, print & pressure-test guide
    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
    [assembly.stl, assembly_section.stl, manifold.stl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]
2026-06-25 Add Makefile with dependency-tracked build steps
    Targets: all, parts, assembly, deps, clean, help. Prerequisites follow the
    module import chain so editing a shared module rebuilds dependents. README
    build section updated to use make.
2026-06-25 Add reference solenoid model + color-coded assembly renders
    - cad/solenoid_model.py: reference coil can + plunger (bought, not printed),
    built in block-local coords so it seats in the coil bore and the plunger
    tip lands in the poppet bore automatically.
    - assembly.py: include the solenoid, color-code each part, emit both an
    exterior (assembly.png) and a corrected Y=0 section (assembly_section.png)
    showing the full fit (manifold -> block -> plunger -> coil).
    - Makefile: refs target + wiring; README parts table updated.
    [assembly.stl, assembly_section.stl, solenoid_coil.stl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]
2026-06-25 Flip valve to pressure-to-close force orientation
    Reroute solenoid_block so supply fills the chamber (via a -X off-axis riser
    from the bottom manifold port) and the orifice drains DOWN to a +X outlet.
    Now supply pressure presses the poppet onto the seat, so pressure helps seal
    and the return spring is a light reseat-only spring. The solenoid opens from
    the seated gap where coil force peaks; coil sets max orifice (A=F/P).
    Manifold/stacking and poppet/gasket/solenoid models unchanged. Docs updated
    (BRIEF force balance, README flow diagram, RESEARCH insight, PRINT_AND_TEST
    spring sizing + pneumatic note). Section render regenerated.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
    [assembly.stl, assembly_section.stl, solenoid_block.stl]
2026-07-08 Add solids-handling pump subsystem (S-valve + vertical submersible variant)
    Extend the repo beyond gas valves with 3D-printable positive-displacement
    pumps for fluids carrying suspended solids (glass beads in mineral oil),
    sized so every bead-wetted passage stays >= 4x the design bead (enforced
    at build time by a clog guard).
    Horizontal twin-cylinder S-valve pump:
    - cylinder_block, s_tube (swept swing valve), wear_ring (TPU face seal),
    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
    [crankshaft.stl, cylinder_block.stl, piston.stl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]
2026-07-08 docs: present the two pump versions side by side
    Restructure the README pump section into "Pumps — two versions" with a
    comparison table + equal horizontal/vertical subsections, cross-link
    PUMP.md <-> VPUMP.md, and note both pumps in Status.
